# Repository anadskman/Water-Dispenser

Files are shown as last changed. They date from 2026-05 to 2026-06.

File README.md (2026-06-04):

# Water-Dispenser

A custom-built smart drink dispenser that mixes water and blackcurrant concentrate on demand using two independently controlled pumps. The system is powered by an ESP32 and features adjustable mixing ratios, WiFi connectivity, cooling support, and a custom PCB.

## Overview

The dispenser stores water and blackcurrant concentrate in separate containers. When the dispense button is pressed, both pumps activate and mix the liquids through a shared output nozzle. The ESP32 controls the pump speeds, allowing the drink strength to be adjusted either through a potentiometer or a future web interface.

## Features

- Adjustable water-to-syrup ratio
- ESP32-based control system
- Custom PCB designed in KiCad
- Food-safe tubing and liquid path
- Physical dispense button
- Potentiometer for ratio adjustment
- Status LED

---

## Hardware

### Fluid System

- 2L water bottle
- 2L blackcurrant concentrate bottle
- 2× 12V peristaltic pumps
- Food-safe silicone tubing
- Barbed Y-connector
- Single output nozzle

### Electronics

- ESP32-WROOM
- 12V DC barrel jack
- LM2596 buck converter
- 3.3V regulator
- 2× Logic-level MOSFETs
- 2× Flyback diodes
- 2× 100Ω gate resistors
- 2× 10kΩ pull-down resistors
- 10kΩ potentiometer
- Pushbutton
- Status LED
- 220Ω LED resistor
- Decoupling and smoothing capacitors

---

## Electronics Design

The schematic is centered around an ESP32-WROOM module.

Power enters through a 12V barrel jack and is split into two sections. The pumps run directly from the 12V rail, while an LM2596 buck converter steps the voltage down before a 3.3V regulator supplies power to the ESP32.

Each pump is controlled by a dedicated MOSFET driver circuit. A 100Ω gate resistor is used between the ESP32 and MOSFET gate, while a 10kΩ pull-down resistor ensures the pumps remain off during boot. Flyback diodes protect the electronics from motor-induced voltage spikes.

A pushbutton is connected using the ESP32's internal pull-up resistor, while a 10k potentiometer provides live adjustment of the syrup ratio. A status LED indicates operating state.

All grounds are shared throughout the system, and capacitors are used for voltage smoothing and noise reduction.

---

## PCB Design

The PCB was designed in KiCad.

### Design Process

1. Created the schematic and assigned footprints.
2. Performed the initial PCB layout.
3. Routed all traces.
4. Ran DRC checks and fixed any issues.
5. Ensured nothing was placed inside the ESP32 keep-out zone.
6. Exported the PCB as a STEP file.
7. Imported the PCB into Fusion 360.

---

## Enclosure Design

The enclosure was designed around the PCB and bottle mounting system.

### Design Changes

- Moved the LED, potentiometer, and button to the opposite side for better usability and appearance.
- Added a cutout for the barrel jack.
- Flipped the PCB orientation after discovering the bottle mounts blocked access to the power connector.
- Designed a dedicated PCB housing.
- Created a removable rear panel.
- Added mounting points for both pumps.
- Designed bottle mounts that allow the dispenser assembly to sit above the bottles.
- Added a central passage for routing outlet tubing.
- Planned to reverse one pump orientation to simplify tube routing.

---

## Current Status

### Completed

- [x] Project planning
- [x] Schematic design
- [x] PCB design and routing
- [x] DRC validation
- [x] STEP export
- [x] Fusion 360 integration
- [x] Enclosure design
- [x] Pump mounts
- [x] Bottle mounting system
- [x] Rear access panel

---

## Bill of Materials (BOM)

| Item | Description | Qty | Price (€) | Total (€) |
|---|---|-----|---|---|
| DC Power Jack | Socket DC Connectors | 1 | 1.46 | 1.46 |
| DC 12V Dosing Pump | Peristaltic Pump | 2 | 6.38 | 6.38 |
| ESP32 Development Board | CH340C | 1 | 5.32 | 5.32 |
| LM2596 Chip | DC Converter | 1 | 0.82 | 0.82 |
| AMS1117-3.3 | 3.3V Regulator | 1 | 1.48 | 1.48 |
| 16V 100µF Electrolytic Capacitor | Capacitor | 1 | 1.94 | 1.94 |
| 100nF Ceramic Capacitor | Decoupling Capacitor | 1 | 2.72 | 2.72 |
| Food-Grade Silicone Tubing | 4mm ID × 5mm OD | 1 | 0.99 | 0.99 |
| 2-Pin Screw Terminals | 2P Terminal Block | 2 | 2.24 | 4.48 |
| IRLZ44N | Logic-Level N-Channel MOSFET | 1 | 3.04 | 3.04 |
| Flyback Diodes | 1N4007 | 1 | 1.72 | 1.72 |
| 100Ω Gate Resistors | Gate Resistors | 2 | Owned | Owned |
| 10kΩ Pull-Down Resistors | Pull-Down Resistors | 2 | Owned | Owned |
| Momentary Pushbutton | 6mm Tactile Switch | 1 | Owned | Owned |
| Potentiometer Bourns 3386P Vertical | 10kΩ | 1 | 2.16 | 2.16 |
| LED | Red | 1 | Owned | Owned |
| 220Ω Resistor | LED Current Limiting Resistor | 1 | Owned | Owned |
| PCB | Water Dispenser PCB (5 pcs) | 5 | 11.79 | 11.79 |

### Cost Summary

| Item | Cost (€) |
|---|---|
| Parts Total | 44.30 |
| Shipping | 6.44 |
| **Grand Total** | **50.74** |

---

## Project Goals

The aim of this project is to create a compact, professional-looking drink dispenser that can accurately mix and dispense flavoured drinks while serving as a complete electronics, PCB design, firmware, and mechanical CAD project.

## Gallery

### PCB



### CAD



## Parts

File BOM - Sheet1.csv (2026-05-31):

Item | Description | Qty | Price(€) | URL | Total
DC Power Jack | Socket DC Connectors | 1 | 1.46 | https://www.aliexpress.com/item/4001206395694.html?pdp_ext_f=%7B"order"%3A"3096"%2C"eval"%3A"1"%2C"fromPage"%3A"search"%7D | 1.46
DC 12V Dosing Pump | Peristaltic Pump | 2 | 6.38 | https://www.aliexpress.com/item/1005006671106432.html?src=google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 | 6.38
ESP32 Development Board | CH340C | 1 | 5.32 | https://www.aliexpress.com/item/1005008806241325.html?pdp_ext_f=%7B"order"%3A"347"%2C"spu_best_type"%3A"price"%2C"eval"%3A"1"%2C"fromPage"%3A"search"%7D&search_p4p_id=2026053113125210174717901627580003672612_3 | 5.32
LM2596 Chip | DC Converter | 1 | 0.82 | https://www.aliexpress.com/item/1005006277955527.html?pdp_ext_f=%7B"order"%3A"206"%2C"eval"%3A"1"%2C"fromPage"%3A"search"%7D | 0.82
AMS1117-3.3 | 3.3V regulator | 1 | 1.48 | https://www.aliexpress.com/item/1005007537334074.html?pdp_ext_f=%7B"order"%3A"3414"%2C"spu_best_type"%3A"price"%2C"eval"%3A"1"%2C"fromPage"%3A"search"%7D&search_p4p_id=202605311333132605134097347480003771266_1 | 1.48
16V 100µF electrolytic capacitor | Capacitor | 1 | 1.94 | https://www.aliexpress.com/item/1005008942188885.html?pdp_ext_f=%7B"order"%3A"2809"%2C"eval"%3A"1"%2C"fromPage"%3A"search"%7D | 1.94
100NF ceramic capacitor | Decoupling | 1 | 2.72 | https://www.aliexpress.com/item/1005011747293156.html?pdp_ext_f=%7B"order"%3A"1424"%2C"spu_best_type"%3A"price"%2C"eval"%3A"1"%2C"fromPage"%3A"search"%7D | 2.72
Food-grade silicone tubing | ID 4mm x 5mm OD | 1 | 0.99 | https://www.aliexpress.com/item/1005001482213878.html?pdp_ext_f=%7B"order"%3A"13815"%2C"eval"%3A"1"%2C"fromPage"%3A"search"%7D&search_p4p_id=2026053113424614320627259427830003738309_1 | 0.99
2-pin screw terminals | 2P | 2 | 2.24 | https://www.aliexpress.com/item/32246655621.html?pdp_ext_f=%7B"order"%3A"84"%2C"eval"%3A"1"%2C"fromPage"%3A"search"%7D | 4.48
IRLZ44N | logic-level N-channel MOSFETs | 1 | 3.04 | https://www.aliexpress.com/item/1005007132690493.html?pdp_ext_f=%7B"order"%3A"1680"%2C"spu_best_type"%3A"price"%2C"eval"%3A"1"%2C"fromPage"%3A"search"%7D&search_p4p_id=202605311349033395446432512200003379633_2 | 3.04
Flyback Diodes | 1N4007 | 1 | 1.72 | https://www.aliexpress.com/item/1005009923993443.html?pdp_ext_f=%7B"order"%3A"2163"%2C"eval"%3A"1"%2C"fromPage"%3A"search"%7D | 1.72
100Ω gate resistors | Gate Resistors | 2 | Owned | Null | Owned
10kΩ pull-down resistors | Pull Down Resistors | 2 | Owned | Null | Owned
momentary pushbutton | 6mm tactile switch | 1 | Owned | Null | Owned
Potentiometer Bourns 3386P Vertical | 10K Ohms | 1 | 2.16 | https://www.aliexpress.com/item/1005006778849942.html?pdp_ext_f=%7B"order"%3A"131"%2C"eval"%3A"1"%2C"fromPage"%3A"search"%7D | 2.16
LED | RED | 1 | Owned | Null | Owned
220Ω resistor | resistor | 1 | Owned | Null | Owned
PCB | Water Dispenser PCB | 5 | 11.79 | https://cart.jlcpcb.com/quote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 | 11.79
 |  |  |  | Shipping | 6.44
 |  |  | Orginal prices above | Total | 50.74

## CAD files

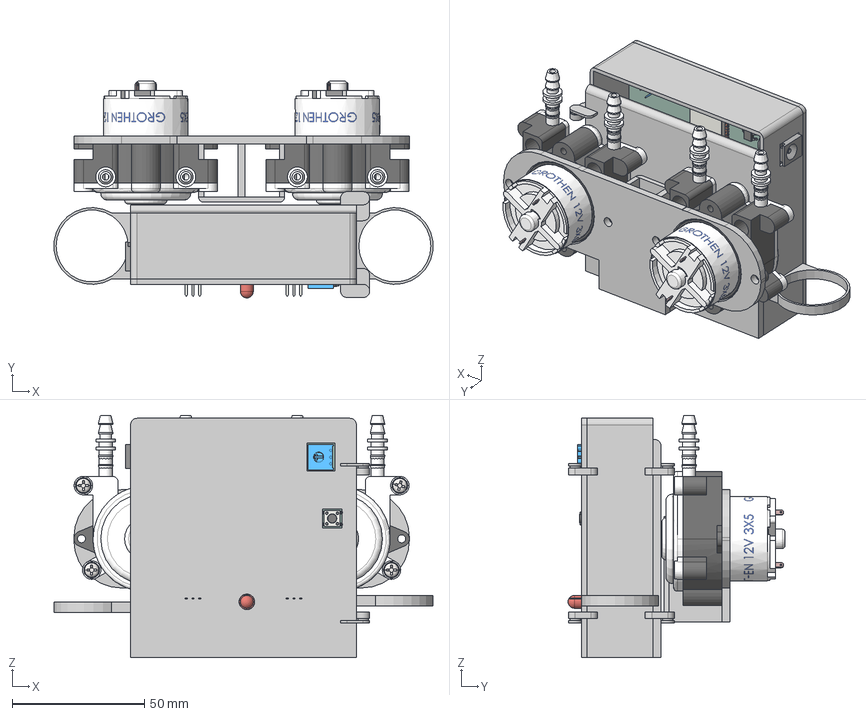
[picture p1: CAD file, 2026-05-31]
CAD/Water Dispenser Assembled.step
143.1 x 81.9 x 91.4 mm
CUI_DEVICES_PJ-102AH
TerminalBlock_Phoenix_MKDS-1,5-2-5.08_1x02_P5.08mm_Horizontal x 2
SW_PUSH_6mm_H4.3mm
R_Axial_DIN0207_L6.3mm_D2.5mm_P5.08mm_Vertical x 5
LED_D5.0mm
ESP32-WROOM-32
TO-220-3_Vertical x 2
D_DO-41_SOD81_P10.16mm_Horizontal x 2
.step 1.11.1
SOT-223
Water Dispenser_PCB
PCB Case
Pump case x 2
12V DC engine x 2
Lower roller holder x 2
Roller x 6
Upper roller holder x 2
Pump cover x 2
Silicone tube 3x5mm x 2
ISO7046 M2.5x5mm x 4
Tapping screw DIN 7049 ST2.9x9.5 x 8
Fitting x 4

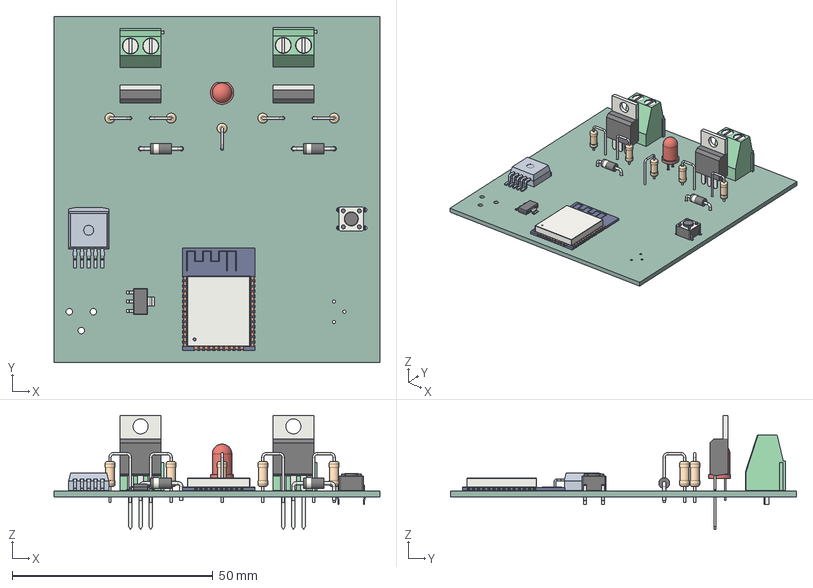
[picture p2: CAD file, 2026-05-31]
CAD/waterdispenserpcb2.step
81.3 x 86.4 x 28.5 mm
TerminalBlock_Phoenix_MKDS-1,5-2-5.08_1x02_P5.08mm_Horizontal x 2
SW_PUSH_6mm_H4.3mm
R_Axial_DIN0207_L6.3mm_D2.5mm_P5.08mm_Vertical x 5
LED_D5.0mm
ESP32-WROOM-32
TO-220-3_Vertical x 2
D_DO-41_SOD81_P10.16mm_Horizontal x 2
.step 1.11.1
SOT-223
Water Dispenser_PCB

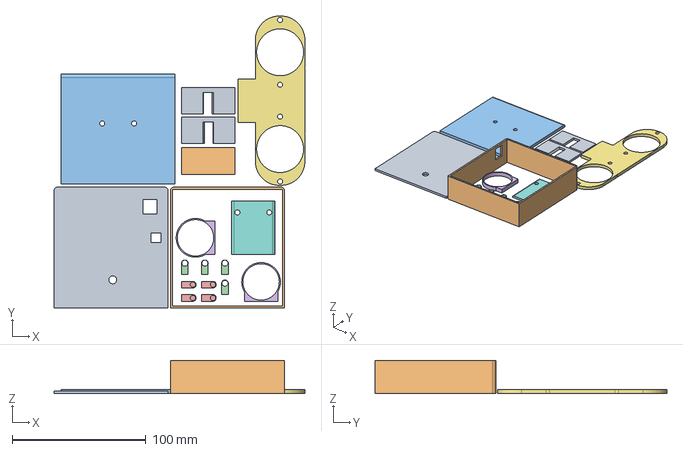
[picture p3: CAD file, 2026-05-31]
CAD/Water Dispenser Print Layout.step
187.6 x 218.4 x 25.0 mm
PCB Case
Pump

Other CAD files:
CAD/Water Dispenser Print layout.stl

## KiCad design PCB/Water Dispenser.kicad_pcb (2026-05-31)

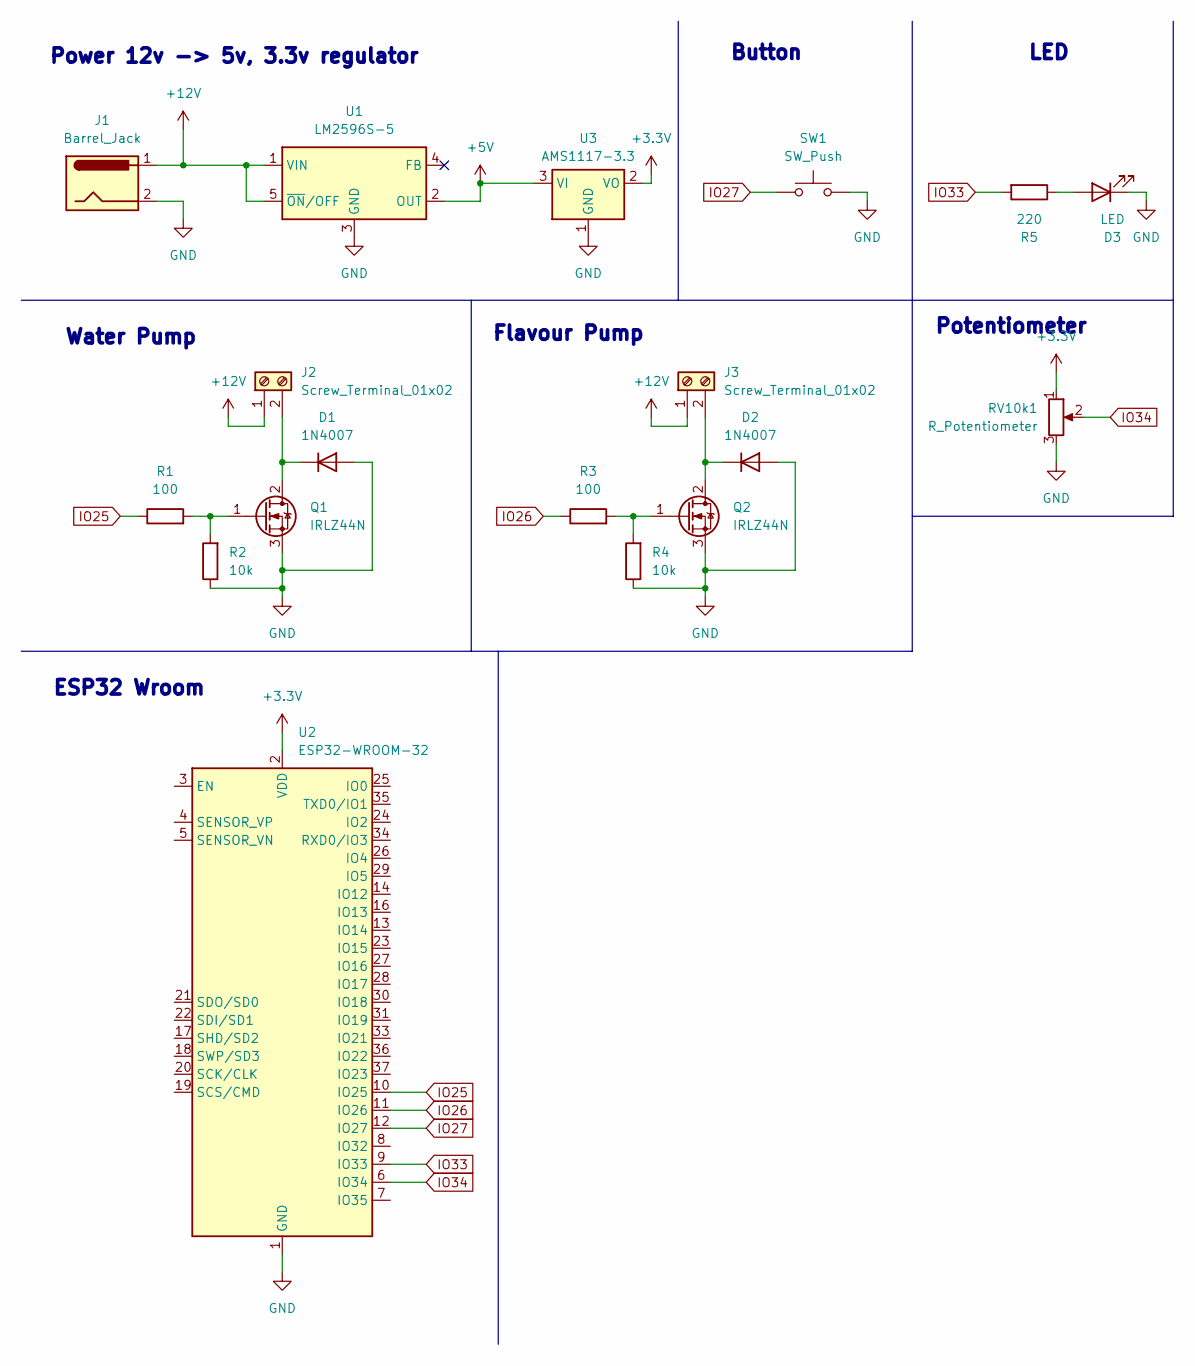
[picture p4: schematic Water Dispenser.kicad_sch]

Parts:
D1, D2: 1N4007; D_DO-41_SOD81_P10.16mm_Horizontal
D3: LED; LED_D5.0mm
J1: Barrel_Jack; BarrelJack_CUI_PJ-102AH_Horizontal
J2, J3: Screw_Terminal_01x02; TerminalBlock_Phoenix_MKDS-1,5-2-5.08_1x02_P5.08mm_Horizont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
Q1, Q2: IRLZ44N; TO-220-3_Vertical
R1, R3: 100; R_Axial_DIN0207_L6.3mm_D2.5mm_P5.08mm_Vertical
R2, R4: 10k; R_Axial_DIN0207_L6.3mm_D2.5mm_P5.08mm_Vertical
R5: 220; R_Axial_DIN0207_L6.3mm_D2.5mm_P5.08mm_Vertical
RV10k1: R_Potentiometer; Potentiometer_Bourns_3386P_Vertical
SW1: SW_Push; SW_PUSH_6mm_H4.3mm
U1: LM2596S-5; TO-263-5_TabPin3
U2: ESP32-WROOM-32
U3: AMS1117-3.3; SOT-223-3_TabPin2

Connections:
+3.3V: RV10k1.1, U2.2 (VDD), U3.2 (VO)
+5V: U1.2 (OUT), U3.3 (VI)
+12V: J1.1, J2.1, J3.1, U1.1 (VIN), U1.5 (~ON/OFF)
GND: D1.2 (A), D2.2 (A), D3.1 (K), J1.2, Q1.3 (S), Q2.3 (S), R2.1, R4.1, RV10k1.3, SW1.2, U1.3 (GND), U2.1 (GND), U2.15 (GND), U2.38 (GND), U2.39 (GND), U3.1 (GND)
IO25: R1.1, U2.10 (IO25)
IO26: R3.1, U2.11 (IO26)
IO27: SW1.1, U2.12 (IO27)
IO33: R5.2, U2.9 (IO33)
IO34: RV10k1.2, U2.6 (IO34)
unnamed: D1.1 (K), J2.2, Q1.2 (D)
unnamed: D2.1 (K), J3.2, Q2.2 (D)
unnamed: D3.2 (A), R5.1
unnamed: Q1.1 (G), R1.2, R2.2
unnamed: Q2.1 (G), R3.2, R4.2

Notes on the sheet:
Flavour Pump
LED
Water Pump
Button
Potentiometer
ESP32 Wroom
Power 12v -> 5v, 3.3v regulator

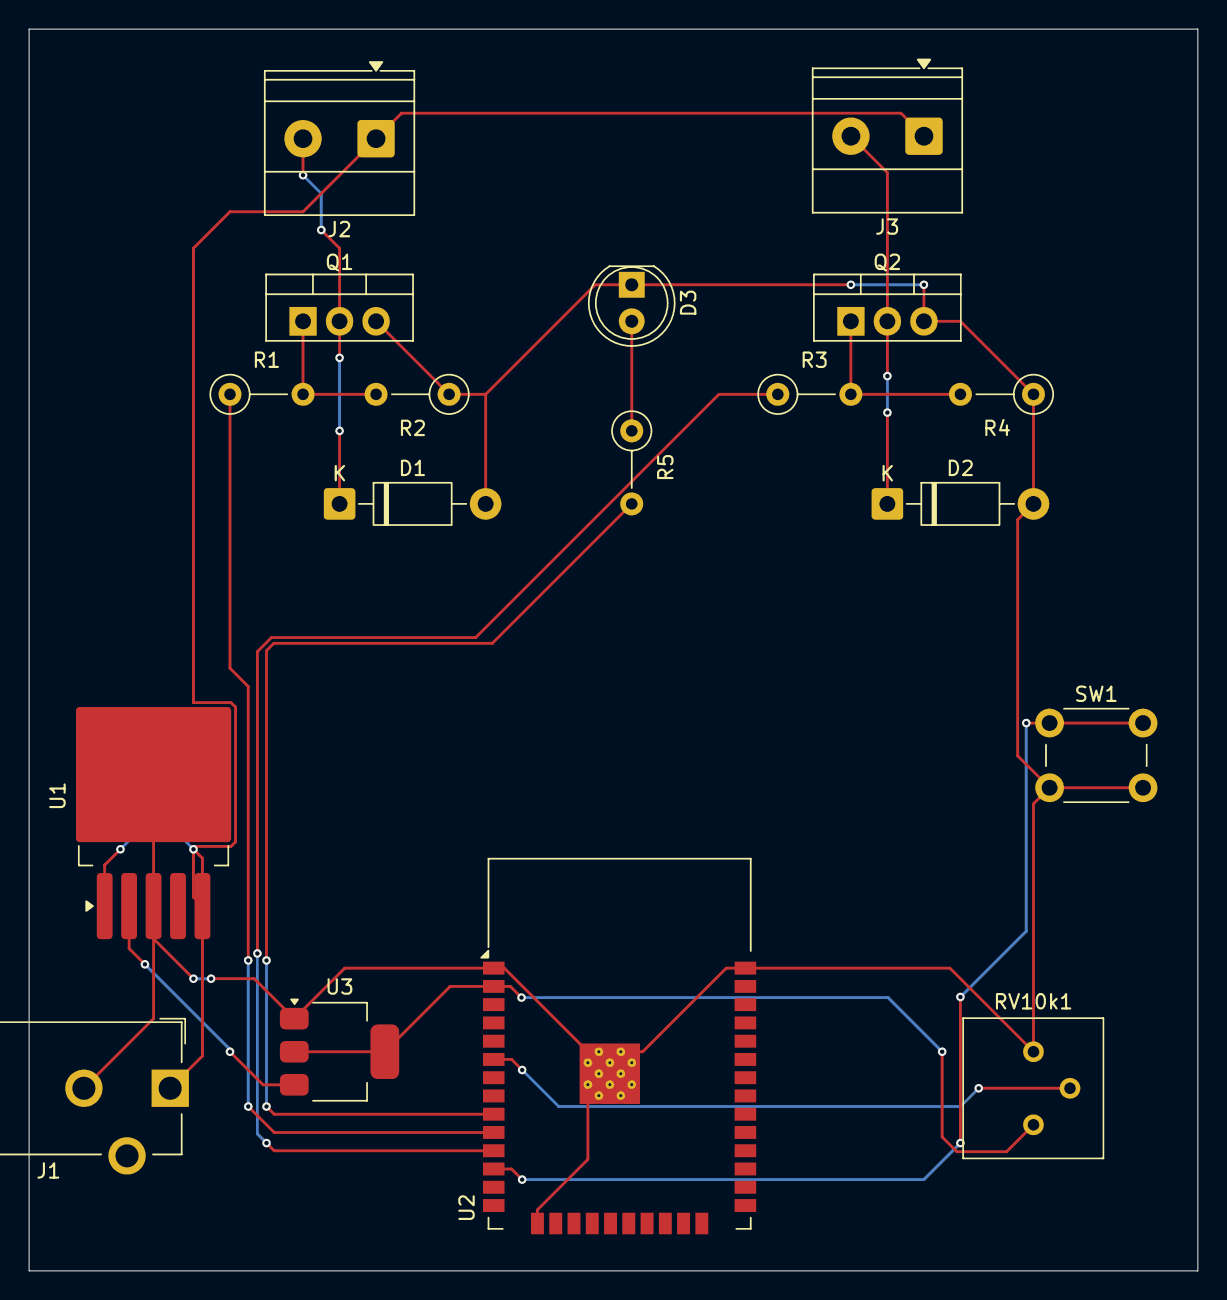
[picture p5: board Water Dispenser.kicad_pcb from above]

Board: 2 copper layers, 81.3 x 86.4 mm, 18 parts (0 on the bottom side), 14 nets.

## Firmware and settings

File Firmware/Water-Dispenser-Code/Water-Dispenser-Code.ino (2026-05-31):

const int WATER_PUMP = 25;
const int SYRUP_PUMP = 26;
const int BUTTON_PIN = 27;
const int POT_PIN = 34;
const int LED_PIN = 33;

// PWM settings
const int PWM_FREQ = 1000;
const int PWM_RESOLUTION = 8;

const int WATER_CHANNEL = 0;
const int SYRUP_CHANNEL = 1;

// Dispense time in milliseconds
const int DISPENSE_TIME = 3000;

void setup() {

  pinMode(BUTTON_PIN, INPUT_PULLUP);
  pinMode(LED_PIN, OUTPUT);

  // ESP32 PWM setup
  ledcSetup(WATER_CHANNEL, PWM_FREQ, PWM_RESOLUTION);
  ledcAttachPin(WATER_PUMP, WATER_CHANNEL);

  ledcSetup(SYRUP_CHANNEL, PWM_FREQ, PWM_RESOLUTION);
  ledcAttachPin(SYRUP_PUMP, SYRUP_CHANNEL);

  digitalWrite(LED_PIN, LOW);

  // Make sure pumps start off
  ledcWrite(WATER_CHANNEL, 0);
  ledcWrite(SYRUP_CHANNEL, 0);
}

void loop() {

  if (digitalRead(BUTTON_PIN) == LOW) {

    digitalWrite(LED_PIN, HIGH);

    int potValue = analogRead(POT_PIN);

    // Map pot to syrup pump speed
    // 25 = weak drink
    // 128 = strong drink
    int syrupPWM = map(potValue, 0, 4095, 25, 128);

    // Water pump full speed
    ledcWrite(WATER_CHANNEL, 255);

    // Syrup pump adjustable speed
    ledcWrite(SYRUP_CHANNEL, syrupPWM);

    delay(DISPENSE_TIME);

    // Stop pumps
    ledcWrite(WATER_CHANNEL, 0);
    ledcWrite(SYRUP_CHANNEL, 0);

    digitalWrite(LED_PIN, LOW);

    delay(300);
  }
}

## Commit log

2026-05-31 Uploaded all files
    [BOM - Sheet1.csv, Water Dispenser Assembled.step, Water Dispenser Print Layout.step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]
2026-05-31 Update README.md to remove screenshot placeholders
    Removed placeholder text for screenshots in PCB and CAD sections.
2026-06-04 Update README with BOM and Cost Summary
    Added Bill of Materials (BOM) and Cost Summary sections to README.
2026-06-04 stl file
    [Water Dispenser Print layout.stl]
